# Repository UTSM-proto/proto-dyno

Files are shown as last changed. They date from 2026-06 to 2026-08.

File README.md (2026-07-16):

# proto-dyno

Simple Python dyno load controller for ATORCH DL24/DL24P-style USB serial electronic loads.

The app treats the load bank as a variable road load / hill resistance for a motor-generator dyno. It presents a watts slider, reads live telemetry, and uses conservative software safety clamps.

## Safety Defaults

This software intentionally defaults far below advertised DL24 ratings:

- max power: 50 W
- max current: 3 A
- max voltage: 36 V
- minimum voltage: 2.5 V
- max temperature: 70 C
- update rate: 2 Hz
- telemetry timeout: 2 seconds

Cheap DL24-style loads are often advertised around 150 W / 180 W, but those ratings are not safe continuous dyno limits. Start low, keep airflow on the load, and validate with external meters.

The app immediately attempts to stop the load if:

- voltage rises above the configured maximum
- voltage falls below the configured minimum while load is enabled
- temperature exceeds the configured maximum
- serial telemetry is lost for more than 2 seconds

## Protocol Status

The known public DL24/PX100-style serial protocol supports:

- output on/off
- current setpoint
- voltage cutoff setpoint
- voltage telemetry
- current telemetry
- temperature telemetry

Native constant-power mode control is not exposed by the simple working Python examples inspected for this repo. `proto-dyno` therefore defaults to constant-power emulation:

```text
I_target = P_target / V_measured
```

The computed current is clamped to the configured current and power limits before being sent to the load.

## Install

Python 3.10+ is recommended.

```powershell
python -m venv .venv
.\.venv\Scripts\Activate.ps1
python -m pip install -r requirements.txt
```

Tkinter ships with normal python.org Windows installers. If your Python build lacks Tkinter, install a standard CPython build.

## Run

```powershell
python -m proto_dyno.app
```

For a specific port:

```powershell
python -m proto_dyno.app --port COM7
```

To list likely devices:

```powershell
python -m proto_dyno.cli list
```

## Notes

- Plug in the DL24 before launching the app.
- The app looks for likely USB serial adapters such as CH340, USB-SERIAL, CP210x, and FTDI devices.
- The load starts disabled. Move the slider, then press `Enable Load`.
- Press `Stop Load` before changing wiring.
- Keep hardware current limits, fuses, and external meters in the setup. Software clamps are a backup, not the primary protection.

## Dyno Joulemeter Firmware

This repo also includes Arduino firmware for the prototype dyno joulemeter:

```text
dyno_joulemeter_firmware/dyno_joulemeter.ino
```

That sketch reads voltage and ACS712 current through an ADS1115, displays live V/I/P/J on an SSD1306 OLED, and logs CSV-style serial rows for dyno runs. See `dyno_joulemeter_firmware/README.md` for wiring, calibration constants, and library requirements.

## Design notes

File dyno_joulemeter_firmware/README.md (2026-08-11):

# Dyno Joulemeter Firmware

Arduino sketch for the prototype dyno joulemeter board. It measures voltage and current through an ADS1115, estimates live power, integrates run energy in joules, shows values on a small SSD1306 OLED, and broadcasts live output measurements to the vehicle WROVER relay over ESP-NOW.

## Hardware Role

Use this alongside the Python DL24 load slider when the dyno needs an independent meter for generator output:

- voltage sense into ADS1115 `AIN2`
- ACS712 current sensor output into ADS1115 `AIN1`
- SSD1306 OLED on I2C address `0x3C`
- ADS1115 on I2C address `0x48`
- red start/resume button on GPIO `4`, active low
- yellow stop/pause/reset button on GPIO `5`, active low
- ESP32 I2C pins: SDA `8`, SCL `9`
- ESP-NOW broadcast on Wi-Fi channel `1`

## Arduino Libraries

Install these through Arduino IDE Library Manager:

- `Adafruit SSD1306`
- `Adafruit GFX Library`
- `Adafruit ADS1X15`

ESP-NOW and Wi-Fi support come from the ESP32 Arduino core.

## Wireless live telemetry

The dyno C3 sends a versioned `DynoTelemetryPacket` every 500 ms. The packet includes voltage, current, output power, accumulated joulemeter energy, run state, boot ID, and sequence number. It is best-effort and has no outage buffer, so local measurement and the OLED continue if the WROVER or LTE connection is unavailable.

Flash the matching `lte_relay` change from `UTSM-proto/utsm-telem-firmware` to the existing WROVER/A7670 board. Both the car C3 and dyno C3 broadcast on channel 1; the relay keeps a separate newest packet for each source.

Expected dyno serial output at 115200 baud:

```text
Dyno ESP-NOW ready (broadcast, channel 1, every 500 ms)
Dyno ESP-NOW queued seq=12 P=84.215 W
```

Flash `dyno_joulemeter_firmware.ino` to the dyno C3 after flashing the WROVER
relay. The existing live-car C3 can remain
on its current compatible live-telemetry firmware. After flashing the dyno C3,
require both the `Dyno ESP-NOW queued` line above and the relay's matching
`DYNO seq=N delivered` line before treating the wireless path as working.

The old temporary sketch also included `ADS1X58.h`; this checked-in version uses the Adafruit ADS1115 API that the code actually calls.

## Calibration Constants

The important constants live near the top of `dyno_joulemeter_firmware.ino`:

```cpp
const float CURRENT_SENSOR_V_PER_A = 0.066f;
const float VOLTAGE_SCALE = 11.0f;
```

At every boot, the OLED displays **Zeroing current** while the firmware waits
two seconds for the ACS712 to settle and then averages its zero-current output
for three seconds. Keep the dyno stopped with no current flowing throughout
this sequence. ESP-NOW is initialized first so calibration includes the radio's
normal power-state offset. The measured voltage becomes the run's current zero
offset.

Readings within `0.06 A` of calibrated zero and voltage readings within
`0.02 V` of zero are displayed and transmitted as zero to suppress measured
idle noise after applying the voltage-divider scale.

`CURRENT_SENSOR_V_PER_A` is `0.066 V/A`, matching a common ACS712 30 A module. Change it if the installed sensor is a 5 A or 20 A version.

`VOLTAGE_SCALE` matches the installed divider: `10 kOhm` from dyno positive
to ADS1115 AIN2 and `1 kOhm` from AIN2 to ground. The ADC sees
`Vin * 1k / (10k + 1k)`, so the input-voltage multiplier is `11.0`. Keep the
divider installed; do not connect dyno voltage directly to the ADS1115 input.

## Controls

- IDLE: shows live V/I/P and waits for Start.
- RUNNING: starts the timer, accumulates voltage/current averages, and integrates joules.
- PAUSED: shows elapsed time, average voltage, average current, average power, and total joules.
- Start while paused resumes the same run.
- Stop while paused resets back to idle.

Serial output is CSV-style:

```text
millis,elapsed_ms,voltage_v,current_a,power_w,energy_j,state
```

This makes it easy to log the joulemeter output on a laptop while the OLED is used at the dyno.

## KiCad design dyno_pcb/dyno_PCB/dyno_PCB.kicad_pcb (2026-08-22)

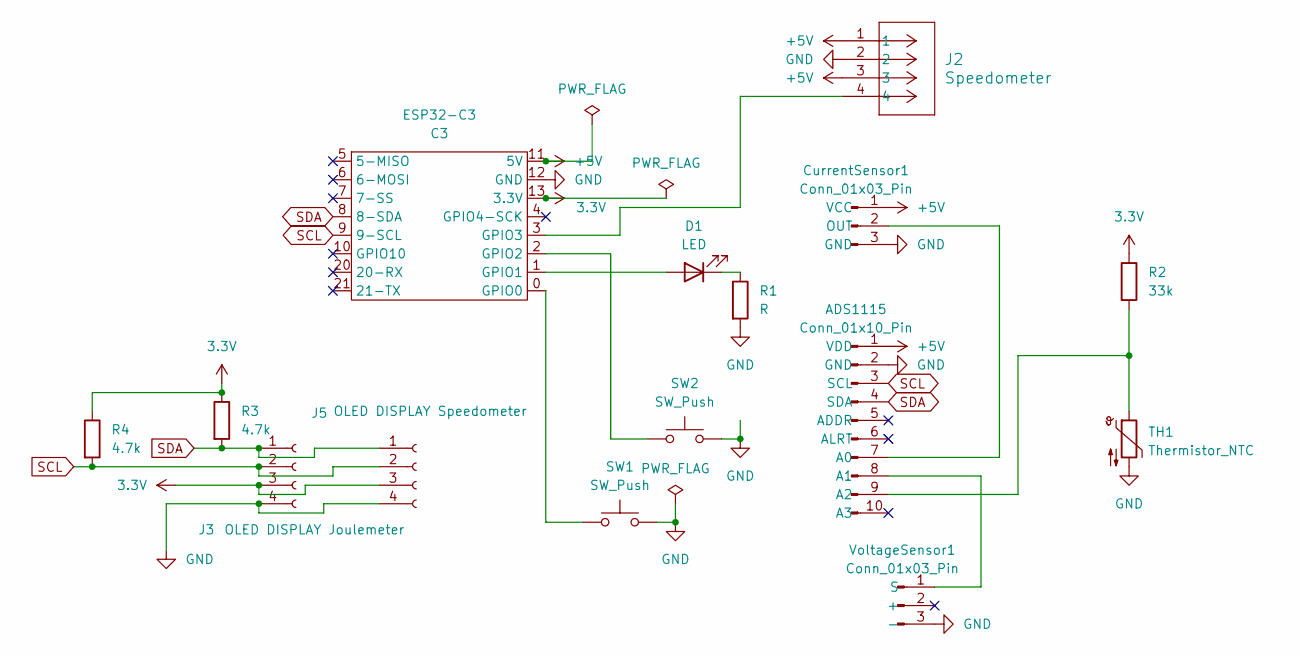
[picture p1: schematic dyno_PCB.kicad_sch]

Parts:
ADS1115: Conn_01x10_Pin; PinSocket_1x10_P2.54mm_Vertical
CurrentSensor1: Conn_01x03_Pin; PinSocket_1x03_P2.54mm_Vertical
D1: LED; LED_D5.0mm
ESP32-C3: C3; ESP32C3
J2: Speedometer; Molex_Mini-Fit_Jr_5566-04A_2x02_P4.20mm_Vertical
J3: OLED DISPLAY Joulemeter; footprintOLEDKicad
J5: OLED DISPLAY Speedometer; footprintOLEDKicad
R1: R; R_Axial_DIN0204_L3.6mm_D1.6mm_P5.08mm_Horizontal
R2: 33k; R_Axial_DIN0204_L3.6mm_D1.6mm_P5.08mm_Horizontal
R3, R4: 4.7k; R_Axial_DIN0204_L3.6mm_D1.6mm_P5.08mm_Horizontal
SW1, SW2: SW_Push; SW_PUSH_6mm_H5mm
TH1: Thermistor_NTC; PinSocket_1x02_P2.54mm_Vertical
VoltageSensor1: Conn_01x03_Pin; PinSocket_1x03_P2.54mm_Vertical

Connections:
3.3V: ESP32-C3.13 (3.3V), J3.3, J5.3, R2.1, R3.1, R4.1
+5V: ADS1115.1 (VDD), CurrentSensor1.1 (VCC), ESP32-C3.11 (5V), J2.1, J2.3
GND: ADS1115.2 (GND), CurrentSensor1.3 (GND), ESP32-C3.12 (GND), J2.2, J3.4, J5.4, R1.2, SW1.2, SW2.2, TH1.2, VoltageSensor1.3 (-)
unnamed: ADS1115.7 (A0), CurrentSensor1.2 (OUT)
unnamed: ADS1115.8 (A1), VoltageSensor1.1 (S)
unnamed: ADS1115.9 (A2), R2.2, TH1.1
unnamed: D1.2 (A), ESP32-C3.1 (GPIO1)
unnamed: D1.1 (K), R1.1
unnamed: ESP32-C3.0 (GPIO0), SW1.1
unnamed: ESP32-C3.2 (GPIO2), SW2.1
unnamed: ESP32-C3.3 (GPIO3), J2.4
SCL: ADS1115.3 (SCL), ESP32-C3.9 (9-SCL), J3.2, J5.2, R4.2
SDA: ADS1115.4 (SDA), ESP32-C3.8 (8-SDA), J3.1, J5.1, R3.2

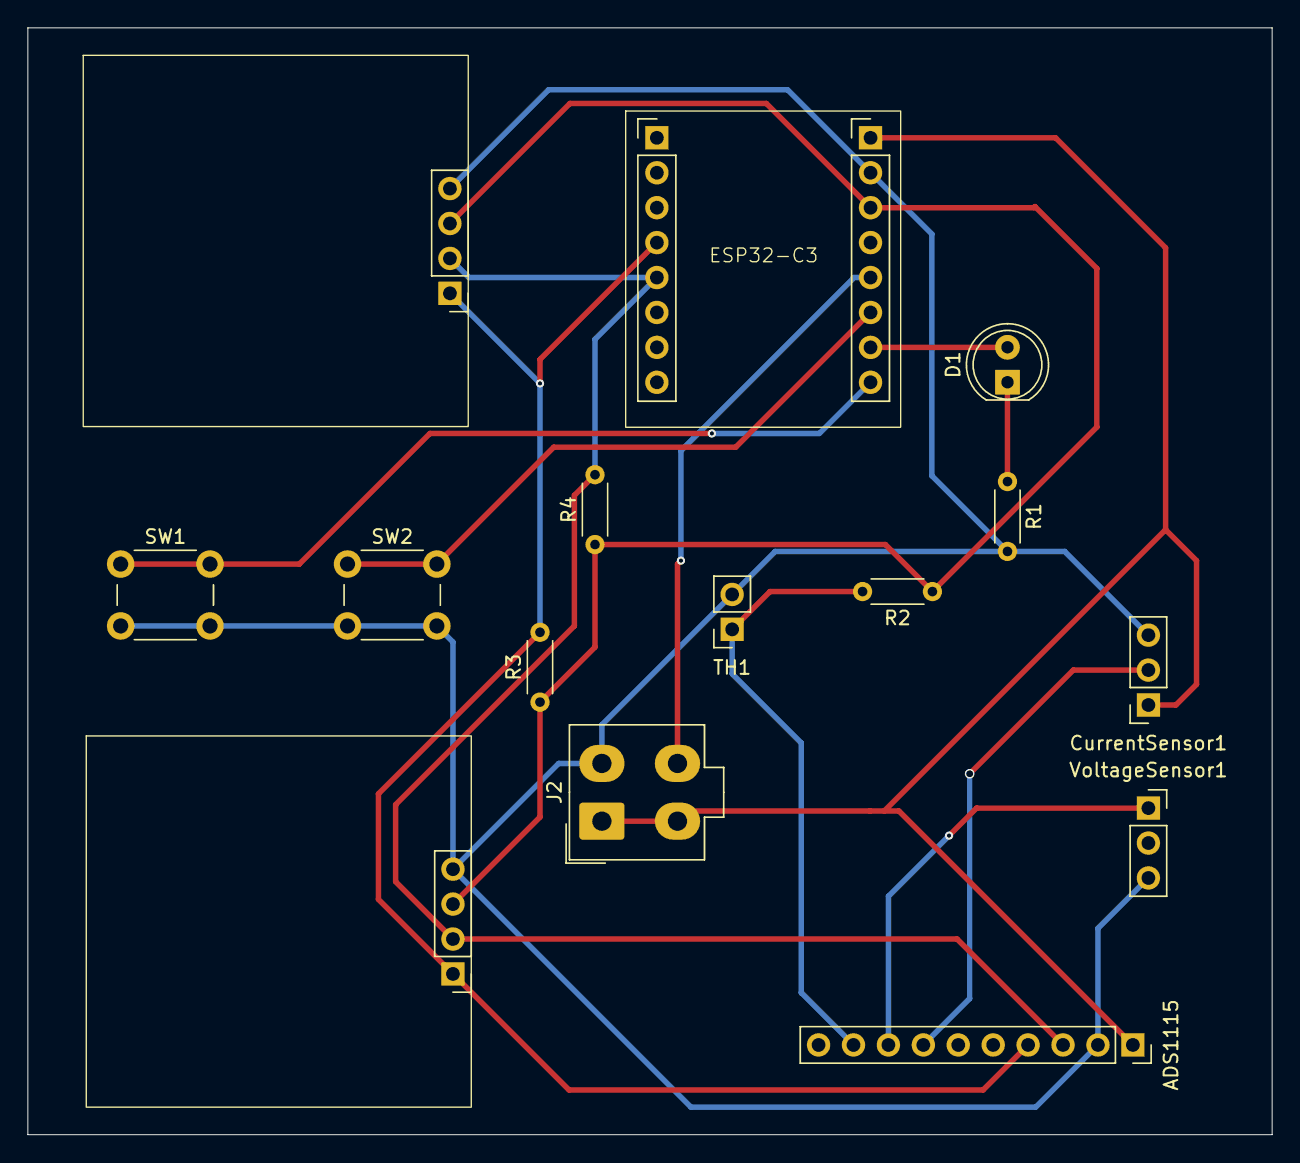
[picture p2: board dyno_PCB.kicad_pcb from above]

Board: 2 copper layers, 90.5 x 80.5 mm, 15 parts (0 on the bottom side), 13 nets.

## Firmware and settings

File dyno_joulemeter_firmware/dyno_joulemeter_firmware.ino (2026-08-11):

#include <Wire.h>
#include <Adafruit_GFX.h>
#include <Adafruit_SSD1306.h>
#include <Adafruit_ADS1X15.h>

#include "dyno_telemetry_espnow.h"

// Dyno joulemeter firmware:
// - ADS1115 AIN2: voltage sense input
// - ADS1115 AIN1: ACS712 current sensor output
// - OLED: live V/I/P/time and paused run summary

Adafruit_ADS1115 ads;

#define SCREEN_WIDTH 128
#define SCREEN_HEIGHT 64

Adafruit_SSD1306 display(SCREEN_WIDTH, SCREEN_HEIGHT, &Wire, -1);
DynoTelemetryEspNowSender telemetrySender;

const int startButtonPin = 4;  // Red button: start/resume
const int stopButtonPin = 5;   // Yellow button: stop/pause/reset

const int I2C_SDA_PIN = 8;
const int I2C_SCL_PIN = 9;
const int ADS1115_ADDR = 0x48;
const int OLED_ADDR = 0x3C;

const int VOLTAGE_ADC_CHANNEL = 2;
const int CURRENT_ADC_CHANNEL = 1;

const float CURRENT_SENSOR_V_PER_A = 0.066f;
// 10 kOhm from dyno+ to AIN2 and 1 kOhm from AIN2 to ground:
// Vin / Vadc = (10k + 1k) / 1k = 11.
const float VOLTAGE_SCALE = 11.0f;
const float CURRENT_DEADBAND_A = 0.06f;
const float VOLTAGE_DEADBAND_V = 0.02f;
const uint32_t CURRENT_ZERO_SETTLE_MS = 2000;
const uint32_t CURRENT_ZERO_CALIBRATION_MS = 3000;

float currentSensorZeroV = 2.582f;

enum TimerState {
  IDLE,
  RUNNING,
  PAUSED
};

TimerState timerState = IDLE;

unsigned long startTime = 0;
unsigned long elapsedTime = 0;
unsigned long lastSampleTime = 0;
unsigned long lastAverageTime = 0;

double voltageTotal = 0.0;
double currentTotal = 0.0;
double energyJ = 0.0;
int averageCount = 0;

struct JoulemeterReading {
  float voltage;
  float current;
  float power;
  float currentSensorVoltage;
};

void setup() {
  Serial.begin(115200);
  Serial.println("millis,elapsed_ms,voltage_v,current_a,power_w,energy_j,state");

  Wire.begin(I2C_SDA_PIN, I2C_SCL_PIN);

  if (!display.begin(SSD1306_SWITCHCAPVCC, OLED_ADDR)) {
    Serial.println("SSD1306 allocation failed");
    for (;;) {
    }
  }

  display.clearDisplay();
  display.setTextColor(SSD1306_WHITE);
  display.setTextSize(1);
  display.setCursor(0, 10);
  display.println("Dyno Joulemeter");
  display.println("Press Start");
  display.display();

  pinMode(startButtonPin, INPUT_PULLUP);
  pinMode(stopButtonPin, INPUT_PULLUP);

  if (!ads.begin(ADS1115_ADDR)) {
    Serial.println("ADS1115 not found");
    while (1) {
    }
  }

  ads.setGain(GAIN_TWOTHIRDS);

  telemetrySender.begin();
  calibrateCurrentZero();
}

void calibrateCurrentZero() {
  display.clearDisplay();
  display.setTextSize(1);
  display.setCursor(0, 8);
  display.println("Zeroing current");
  display.println("Keep dyno stopped");
  display.println("No current/load");
  display.display();

  Serial.println("Waiting for ACS712 to settle with zero current...");
  delay(CURRENT_ZERO_SETTLE_MS);
  Serial.println("Calibrating ACS712 zero for 3 seconds...");

  uint32_t startedMs = millis();
  double voltageSum = 0.0;
  uint32_t sampleCount = 0;
  while (millis() - startedMs < CURRENT_ZERO_CALIBRATION_MS) {
    int16_t raw = ads.readADC_SingleEnded(CURRENT_ADC_CHANNEL);
    voltageSum += ads.computeVolts(raw);
    sampleCount++;
    delay(2);
  }

  if (sampleCount > 0) {
    currentSensorZeroV = voltageSum / sampleCount;
  }
  Serial.printf("ACS712 zero calibrated: %.6f V from %lu samples\n",
                currentSensorZeroV,
                static_cast<unsigned long>(sampleCount));
}

void loop() {
  JoulemeterReading reading = readJoulemeter();

  switch (timerState) {
    case IDLE:
      showIdle(reading);
      logReading(reading, "idle");

      if (buttonPressed(startButtonPin)) {
        startRun();
      }
      break;

    case RUNNING:
      elapsedTime = millis() - startTime;
      integrateEnergy(reading);
      updateAverages(reading);
      displayRun(elapsedTime, reading, true);
      logReading(reading, "running");

      if (buttonPressed(stopButtonPin)) {
        elapsedTime = millis() - startTime;
        timerState = PAUSED;
      }
      break;

    case PAUSED:
      showPaused(elapsedTime, reading);
      logReading(reading, "paused");

      if (buttonPressed(startButtonPin)) {
        startTime = millis() - elapsedTime;
        lastSampleTime = millis();
        timerState = RUNNING;
      } else if (buttonPressed(stopButtonPin)) {
        timerState = IDLE;
      }
      break;
  }

  sendTelemetry(reading);

  delay(100);
}

void sendTelemetry(JoulemeterReading reading) {
  DynoRunState state = DYNO_STATE_IDLE;
  if (timerState == RUNNING) state = DYNO_STATE_RUNNING;
  if (timerState == PAUSED) state = DYNO_STATE_PAUSED;

  telemetrySender.send(
    millis(),
    static_cast<int32_t>(reading.voltage * 1000.0f),
    static_cast<int32_t>(reading.current * 1000.0f),
    static_cast<int32_t>(reading.power * 1000.0f),
    static_cast<uint64_t>(max(0.0, energyJ) * 1000.0),
    state
  );
}

JoulemeterReading readJoulemeter() {
  int16_t rawBattery = ads.readADC_SingleEnded(VOLTAGE_ADC_CHANNEL);
  float voltage = ads.computeVolts(rawBattery) * VOLTAGE_SCALE;
  if (fabsf(voltage) < VOLTAGE_DEADBAND_V) voltage = 0.0f;

  int16_t rawCurrentSensor = ads.readADC_SingleEnded(CURRENT_ADC_CHANNEL);
  float currentSensorVoltage = ads.computeVolts(rawCurrentSensor);
  float current = (currentSensorVoltage - currentSensorZeroV) /
                  CURRENT_SENSOR_V_PER_A;
  if (fabsf(current) < CURRENT_DEADBAND_A) current = 0.0f;

  JoulemeterReading reading;
  reading.voltage = voltage;
  reading.current = current;
  reading.power = voltage * current;
  reading.currentSensorVoltage = currentSensorVoltage;
  return reading;
}

void startRun() {
  startTime = millis();
  elapsedTime = 0;
  lastSampleTime = millis();
  lastAverageTime = 0;
  voltageTotal = 0.0;
  currentTotal = 0.0;
  energyJ = 0.0;
  averageCount = 0;
  timerState = RUNNING;
}

void integrateEnergy(JoulemeterReading reading) {
  unsigned long now = millis();
  if (lastSampleTime == 0) {
    lastSampleTime = now;
    return;
  }

  float dtSeconds = (now - lastSampleTime) / 1000.0f;
  energyJ += reading.power * dtSeconds;
  lastSampleTime = now;
}

void updateAverages(JoulemeterReading reading) {
  if (elapsedTime - lastAverageTime >= 1000) {
    lastAverageTime = elapsedTime;
    voltageTotal += reading.voltage;
    currentTotal += reading.current;
    averageCount++;
  }
}

bool buttonPressed(int pin) {
  if (digitalRead(pin) != LOW) {
    return false;
  }

  delay(50);
  while (digitalRead(pin) == LOW) {
    delay(10);
  }
  return true;
}

void showIdle(JoulemeterReading reading) {
  display.clearDisplay();
  display.setTextSize(1);
  display.setCursor(0, 0);
  display.println("Dyno Joulemeter");
  display.print("V: ");
  display.println(reading.voltage, 3);
  display.print("I: ");
  display.println(reading.current, 3);
  display.print("P: ");
  display.println(reading.power, 2);
  display.print("Sense V: ");
  display.println(reading.currentSensorVoltage, 4);
  display.println("Press Start");
  display.display();
}

void displayRun(unsigned long timeInMillis, JoulemeterReading reading, bool clear) {
  unsigned int minutes = timeInMillis / 60000;
  unsigned int seconds = (timeInMillis % 60000) / 1000;
  unsigned int milliseconds = timeInMillis % 1000;

  char timeStr[12];
  sprintf(timeStr, "%02u:%02u:%03u", minutes, seconds, milliseconds);

  if (clear) {
    display.clearDisplay();
  }

  display.setTextSize(1);
  display.setCursor(0, 0);
  display.print("V: ");
  display.println(reading.voltage, 3);
  display.print("I: ");
  display.println(reading.current, 3);
  display.print("P: ");
  display.println(reading.power, 2);
  display.print("J: ");
  display.println(energyJ, 1);
  display.println(timeStr);

  if (clear) {
    display.display();
  }
}

void showPaused(unsigned long timeInMillis, JoulemeterReading reading) {
  display.clearDisplay();
  displayRun(timeInMillis, reading, false);

  display.print("Avg V: ");
  if (averageCount > 0) {
    display.println((float)voltageTotal / averageCount, 3);
  } else {
    display.println("N/A");
  }

  display.print("Avg I: ");
  if (averageCount > 0) {
    display.println((float)currentTotal / averageCount, 3);
  } else {
    display.println("N/A");
  }

  display.print("Avg P: ");
  if (averageCount > 0) {
    display.println((float)((currentTotal * voltageTotal) / (averageCount * averageCount)), 2);
  } else {
    display.println("N/A");
  }

  display.display();
}

void logReading(JoulemeterReading reading, const char *state) {
  Serial.print(millis());
  Serial.print(",");
  Serial.print(elapsedTime);
  Serial.print(",");
  Serial.print(reading.voltage, 4);
  Serial.print(",");
  Serial.print(reading.current, 4);
  Serial.print(",");
  Serial.print(reading.power, 4);
  Serial.print(",");
  Serial.print(energyJ, 4);
  Serial.print(",");
  Serial.println(state);
}

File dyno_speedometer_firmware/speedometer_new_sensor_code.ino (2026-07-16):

#include <Adafruit_GFX.h>
#include <Adafruit_GrayOLED.h>
#include <Adafruit_SPITFT.h>
#include <Adafruit_SPITFT_Macros.h>
#include <gfxfont.h>

#include <Adafruit_SSD1306.h>
#include <splash.h>

/*
-----------------------------------------
 DYNAMOMETER FLAG SPEED SENSOR WIRING
-----------------------------------------
Sensor: LM393 IR Slotted Speed Sensor Module
Pins on sensor module:
    VCC  → Arduino 5V
    GND  → Arduino GND
    DO   → Arduino DIGITAL PIN 2   (sensorPin)
           (This pin outputs 0/1 depending on whether a flag blocks the IR beam)
-----------------------------------------
*/

#include <Arduino.h>

// -------------------------------------------------
// CONFIGURATION
// -------------------------------------------------

// Number of reflective/mechanical flags on the pulley wheel
#define FLAG_COUNT 8        //Change this depending on actual amounto f flags; I forget how many mech team had

// LM393 digital output pin (DO)
const int sensorPin = 2;     // MUST be a digital pin; this code assumes Arduino UNO D2

// OLED stuff
#define SCREEN_WIDTH 128
#define SCREEN_HEIGHT 64
#define OLED_SLEEP_TIME 3000

Adafruit_SSD1306 display(SCREEN_WIDTH, SCREEN_HEIGHT, &Wire, -1);

unsigned long lastChangeTime = 0;
bool displaySleeping = false;

// SPEED Stuff
#define GEAR_RATIO 3.33333333 // 3:1
#define CONVERT_TO_KM_H 0.06 // 60/1000
#define CIRCUM_SMALL 0.2 // Circumference of small gear is ~20cm

// -------------------------------------------------
// FILTERING / HISTORY BUFFERS
// -------------------------------------------------
long rpmHistory[5]   = {0,0,0,0,0};
long speedHistory[5] = {0,0,0,0,0};

long rpmFiltered = 0;
long speedFiltered = 0;

void updateHistoryArrays(long rpmVal, long speedVal) {
    for (int i = 0; i < 4; i++) {
        rpmHistory[i]   = rpmHistory[i+1];
        speedHistory[i] = speedHistory[i+1];
    }
    rpmHistory[4]   = rpmVal;
    speedHistory[4] = speedVal;

    long rpmSum = 0;
    long speedSum = 0;
    for (int i = 0; i < 5; i++) {
        rpmSum   += rpmHistory[i];
        speedSum += speedHistory[i];
    }

    rpmFiltered   = rpmSum / 5;
    speedFiltered = speedSum / 5;
}

// -------------------------------------------------
// INTERRUPT SYSTEM
// -------------------------------------------------
volatile unsigned long lastPulseMicros = 0;
volatile unsigned long pulseIntervalMicros = 0;
volatile bool newPulse = false;

void pulseISR() {
    unsigned long now = micros();
    unsigned long dt = now - lastPulseMicros;

    // Reject impossible pulses / chatter
    if (dt < 500) return;   // tune this threshold

    pulseIntervalMicros = dt;
    lastPulseMicros = now;
    newPulse = true;
}

// -------------------------------------------------
// SENSOR EDGE DETECTION
// -------------------------------------------------

bool previousFlagState = false;   // previous state of DO pin
bool flagState         = false;   // current state of DO pin

// Detect a flag passing through the slotted sensor
// One pulse per flag: output only on LOW to HIGH transistion,
// then require it to go back LOW before rearming
/*
bool detectFlag() {
    static bool armed = true;  // ready to detect next flag entry

    int raw = digitalRead(sensorPin);      // DO pin
    bool flagPresent = (raw == HIGH);      // something obstructing sensor

    if (armed && flagPresent) {
        armed = false;                    // lock out until flag leaves
        Serial.println("FLAG DETECTED");  // debug output - worked as of Jan 28
        Serial.println(""); 
        Serial.println("PIN STATE:");
        Serial.println(raw);
        return true;                      // only one pulse per flag
    }

    if (!flagPresent) {
        armed = true;                     // rearm once flag is gone
    }

    return false;
}*/
// revised detection function: require N (can change and tune) lows before rearming (ignore bounces)
bool detectFlag() {
    static bool armed = true;
    static uint8_t lowCount = 0;
    static int N_num = 10; 

    int raw = digitalRead(sensorPin);
    bool flagPresent = (raw == HIGH);

    // Detection: only once per flag
    if (armed && flagPresent) {
        armed = false;
        lowCount = 0;          // reset any pending rearm low counts
        return true;
    }

    // Rearm logic: require N consecutive LOW samples
    if (!flagPresent) {
        if (lowCount < N_num) lowCount++;
        if (lowCount >= N_num) armed = true;
    } else {
        // Any HIGH breaks the "consecutive LOW" streak
        lowCount = 0;
    }

    return false;
}


// -------------------------------------------------
// OLED Functions
// -------------------------------------------------

void updateDisplay(long rpm_current, long rpmFiltered, long speed_current) {

    display.clearDisplay();
    display.setTextSize(2);
    display.setTextColor(SSD1306_WHITE);

    display.setCursor(0, 0);
    display.print("RPM:");
    display.println(rpm_current);

    display.setCursor(0, 20);
    display.print("FRPM:"); // Filtered RPM
    display.println(rpmFiltered);

    display.setCursor(0, 40);
    display.print("SPD:");
    display.println(speed_current);

    display.display();
}



// -------------------------------------------------
// MAIN SETUP
// -------------------------------------------------
void setup() {
    
    pinMode(sensorPin, INPUT); // LM393 module already has pull-up
    attachInterrupt(digitalPinToInterrupt(sensorPin), pulseISR, RISING); // Using interrupts

    Serial.begin(115200);

    // OLED Display
    if(!display.begin(SSD1306_SWITCHCAPVCC, 0x3C)) {
        for(;;); // OLED not found
    }

    display.clearDisplay();
    // display.println("Hello");
    // display.display();
}



// -------------------------------------------------
// MAIN LOOP
// (period measurement using micros() for high resolution)
// -------------------------------------------------
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

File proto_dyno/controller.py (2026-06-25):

from __future__ import annotations

from dataclasses import dataclass
from time import monotonic

from .dl24 import DL24Load, Telemetry
from .safety import SafetyLimits, current_for_power, safety_fault


@dataclass(frozen=True)
class ControlStatus:
    telemetry: Telemetry | None
    requested_power_w: float
    target_current_a: float
    load_enabled: bool
    fault: str | None
    mode: str


class DynoController:
    def __init__(self, load: DL24Load, limits: SafetyLimits):
        limits.validate()
        self.load = load
        self.limits = limits
        self.requested_power_w = 0.0
        self.load_enabled = False
        self.last_telemetry_s: float | None = None
        self.last_fault: str | None = None
        self.native_cp_available = False

    def set_requested_power(self, watts: float) -> None:
        self.requested_power_w = max(0.0, min(float(watts), self.limits.max_power_w))

    def enable(self) -> None:
        self.last_fault = None
        self.load.enable()
        self.load_enabled = True

    def stop(self, reason: str | None = None) -> None:
        try:
            self.load.set_current_a(0.0)
            self.load.stop()
        finally:
            self.load_enabled = False
            if reason:
                self.last_fault = reason

    def poll_once(self) -> ControlStatus:
        telemetry = self.load.read_telemetry()
        self.last_telemetry_s = monotonic()

        fault = safety_fault(telemetry.voltage_v, telemetry.temp_c, self.limits)
        if fault:
            self.stop(fault)
            return ControlStatus(telemetry, self.requested_power_w, 0.0, False, fault, "stopped")

        target_current = 0.0
        mode = "cc-fallback"
        if self.load_enabled:
            if self.native_cp_available and self.load.set_power_w(self.requested_power_w):
                mode = "native-cp"
            else:
                voltage = telemetry.voltage_v or 0.0
                target_current = current_for_power(self.requested_power_w, voltage, self.limits)
                self.load.set_current_a(target_current)

        return ControlStatus(
            telemetry=telemetry,
            requested_power_w=self.requested_power_w,
            target_current_a=target_current,
            load_enabled=self.load_enabled,
            fault=self.last_fault,
            mode=mode,
        )

    def check_telemetry_timeout(self) -> str | None:
        if self.last_telemetry_s is None:
            return None
        age_s = monotonic() - self.last_telemetry_s
        if age_s > self.limits.telemetry_timeout_s:
            reason = f"Telemetry lost for {age_s:.1f} s"
            self.stop(reason)
            return reason
        return None

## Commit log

2026-08-11 Broadcast dyno power over ESP-NOW
2026-08-11 Fix Arduino dyno sketch layout
    [dyno_joulemeter_firmware.ino]
2026-08-11 Document dyno button colors
2026-08-11 Calibrate dyno current at startup
2026-08-11 Calibrate dyno voltage divider
2026-08-11 Calibrate dyno current with radio active
2026-08-15 Erm, I fink dyno pcb is done? el goato
    [dyno_PCB-B_Cu.gbr, dyno_PCB-B_Mask.gbr, dyno_PCB-B_Paste.gbr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]
